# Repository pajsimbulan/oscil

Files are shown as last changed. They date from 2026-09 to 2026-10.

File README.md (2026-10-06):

<p align="center">
  Oscil
</p>

<h3 align="center">A two-channel oscilloscope and function generator, built from three ESP32-S3s</h3>

<p align="center">
  C · ESP-IDF · FreeRTOS · bare-metal drivers · LVGL · KiCad · Supabase
</p>

<p align="center">
  
  
  
  
  
  
</p>

<p align="center">
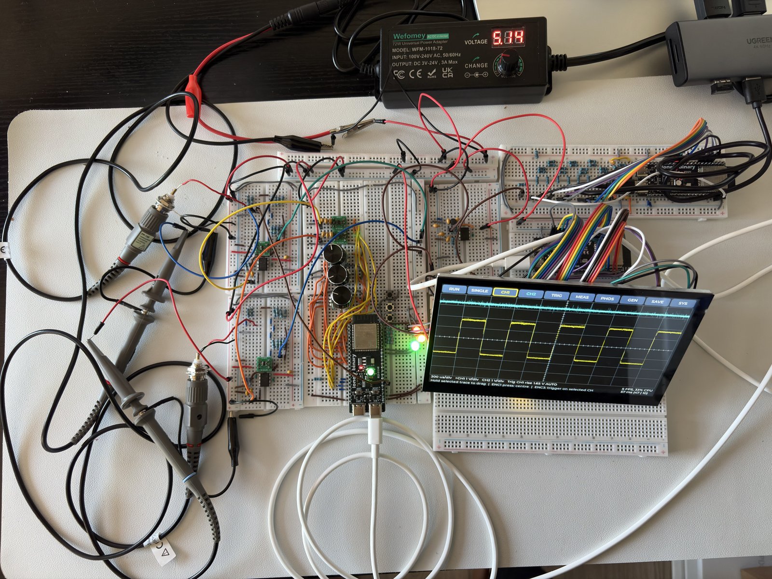
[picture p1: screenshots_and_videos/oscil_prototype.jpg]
The Oscil prototype running on breadboards
  
</p>

Oscil reads two signals and draws them live on a 7 inch touchscreen, and it
can also output sine, square, saw and triangle waves. One board samples,
one runs the screen and one generates. The screen board also joins Wi-Fi,
updates its own firmware and saves screenshots to a cloud account.

I designed and built all of it, the schematic, the breadboard bring-up, the
firmware, the cloud backend and the tests. The build logs below cover every
day of it, bugs included.

**Demos:**
[touch controls](screenshots_and_videos/oscil_touch_controls_demo.mp4) ·
[generator](screenshots_and_videos/oscil_generator_demo.mp4) ·
[firmware update over Wi-Fi](screenshots_and_videos/oscil_ota_update_demo.mp4) ·
[saving to the cloud](screenshots_and_videos/oscil_cloud_save_demo.mp4)

---

## Firmware

| | |
|---|---|
| **Bare-metal drivers** | GPIO, SPI, UART, GDMA and a timer interrupt written from the ESP32-S3 register manual |
| **Sampling** | Two 12-bit ADCs read in one SPI frame at 26.67 MHz, DMA bursts up to about 620 kSa/s, edge trigger, min/max decimation |
| **Board link** | UART at 2 Mbaud with COBS framing and CRC-16, 31.8 frames/s with zero errors |
| **Generator** | DDS in a 100 kHz timer interrupt into an 8-bit R-2R DAC |
| **Display** | LVGL on an 800 x 480 parallel RGB panel, framebuffers in PSRAM, I2C touch |
| **FreeRTOS** | Tasks pinned per core, queues, event groups, notifications, critical sections |
| **Memory** | PSRAM for framebuffers and stacks, code run from PSRAM, ISRs in IRAM, custom partition table, NVS |
| **Connected** | Wi-Fi, HTTPS OTA with self-test and rollback, Supabase sign-in and photo uploads |
| **Tested** | Unity host tests in GitHub Actions, every pin checked on a logic analyzer |

The full list, with the file for each, is in [firmware/README.md](firmware/README.md#firmware-skills).

---

## Repository guide

| Folder | What's inside |
|---|---|
| [`firmware/`](firmware/) | One ESP-IDF project per board, shared C code, host tests, PC tools |
| [`hardware/`](hardware/) | KiCad Rev A schematic, pin map, hardware build log |
| [`software/`](software/) | Supabase schema, account Edge Function, isolation tests |
| [`datasheets/`](datasheets/) | Links to the datasheet revisions the design uses |
| [`screenshots_and_videos/`](screenshots_and_videos/) | Diagrams, photos and demo clips |

---

## Contents

- [Use cases](#use-cases)
- [Architecture](#architecture)
- [Requirements](#requirements)
- [Schematic](#schematic)
- [Build logs](#build-logs)
- [Known limits](#known-limits)
- [What's next](#whats-next)
- [Design documents](#design-documents)
- [Revision history](#revision-history)
- [License](#license)

---

## Use cases

What a user can do with Oscil.

Use cases and functionality

---

## Architecture

Three ESP32-S3 boards linked over UART, with Supabase as the cloud backend.

Architecture

---

## Requirements

### Firmware

How the three ESP32-S3s sample, display, generate and talk to each other.

Firmware requirements

### Hardware

What the hardware has to provide, and why it uses an external ADC and a separate display MCU.

Hardware requirements

### Software

Accounts, screenshot records and file storage on Supabase.

Software requirements

---

## Schematic

Top level of the KiCad Rev A schematic. Each block is its own sheet,
explained in [hardware/](hardware/).

Schematic, top level

**[Full schematic PDF](hardware/docs/Oscil-Schematic-RevA-05-Final.pdf)** ·
[Pin map](hardware/docs/pin-map.md) ·
[Bill of materials](Oscil_bill_of_materials_bom.xlsx)

---

## Build logs

Written as it happened, mistakes included.

<details>
<summary><b>Firmware</b>: from the first blinking LED to cloud saves, with the bugs, the logic analyzer captures and the fixes</summary>

## 2026-09-21

Started firmware. Three ESP-IDF projects, one per board, plus a shared
folder so pin numbers and the link protocol only exist once.

## 2026-09-22

sdkconfig.defaults in each: 16MB flash, octal PSRAM, 1000 Hz tick,
console on USB Serial/JTAG. The 2MB and 100 Hz defaults both bit me
in earlier lab work, so each build gets checked against sdkconfig.

Pin numbers from pin-map.md are in a header per board. Firmware
never uses a raw GPIO number.

AFE scaling in shared. The divider bottom sits on 2.2 V instead of
ground, so 0 V at the BNC reads 1.65 V at the ADC. Vbnc = 4 x (Vadc - 1.65).

First build couldn't find oscil_pins_acq.h. An include path would've
found the header but not compiled the .c, so shared is a real component
now. Also caught display and gen still named project(acq).

Host tests with Unity run the real oscil_afe.c on my PC. 4/4 pass.
They check the math, not the hardware. CI runs them on every push
that touches firmware, and the badge on the README shows the result.

Status LED heartbeat on all three boards. GPIO goes through registers
in oscil_gpio.h, no driver. The WS2812 is bit-banged off the CPU cycle
counter: 24 bits GRB, 0.4 or 0.85 us high in a 1.25 us bit, interrupts
masked for the ~30 us frame. Blink task pinned to core 0.
Acq green, display red, gen blue.

First build died on -Werror=misleading-indentation. A `while (...);`
wait loop with the next line one space off. Empty loops get `{ }` now.
First flash wasn't one either: only the monitor ran, and board 1 was
still booting an old lab.

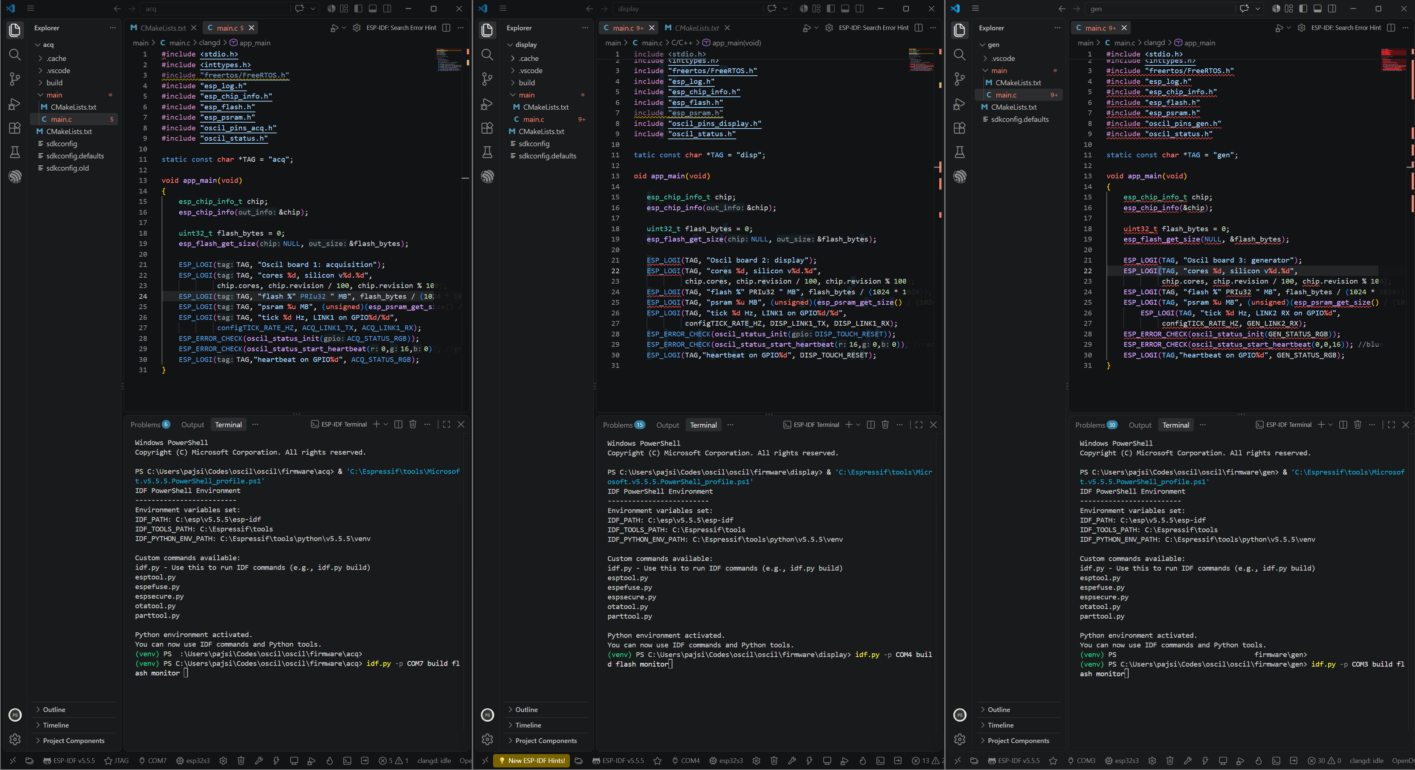
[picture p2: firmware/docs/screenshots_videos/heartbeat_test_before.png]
Before: three projects, one command each


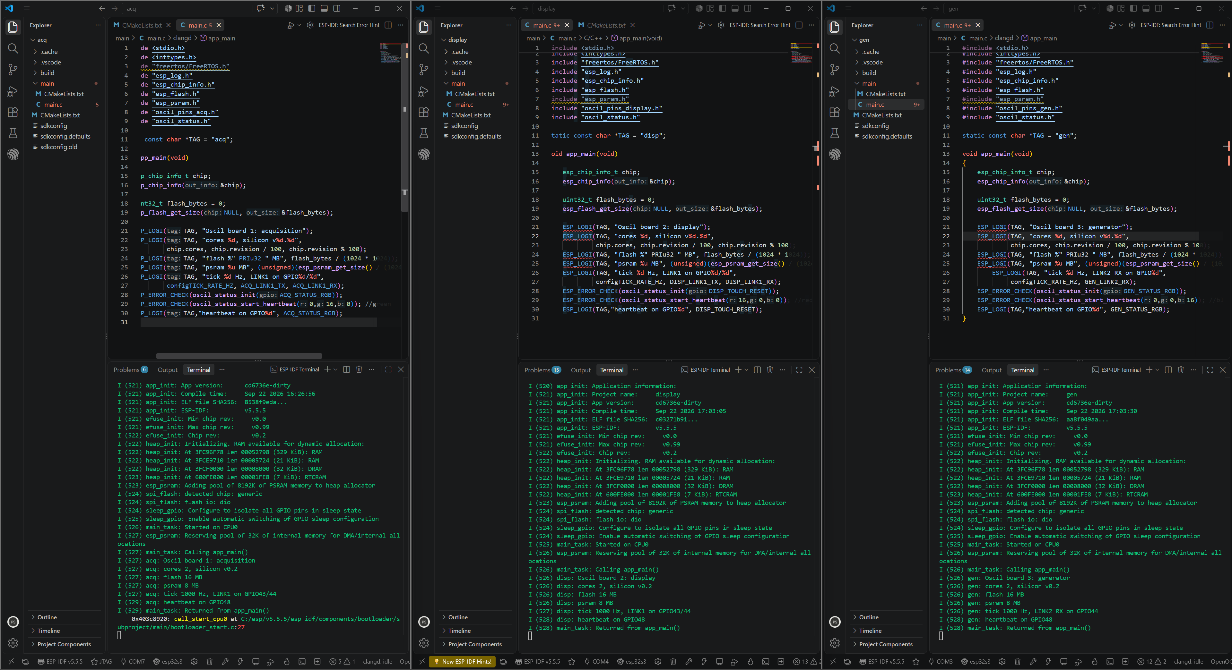
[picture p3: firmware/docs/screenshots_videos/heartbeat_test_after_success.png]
After: all three boot, heartbeat on GPIO48


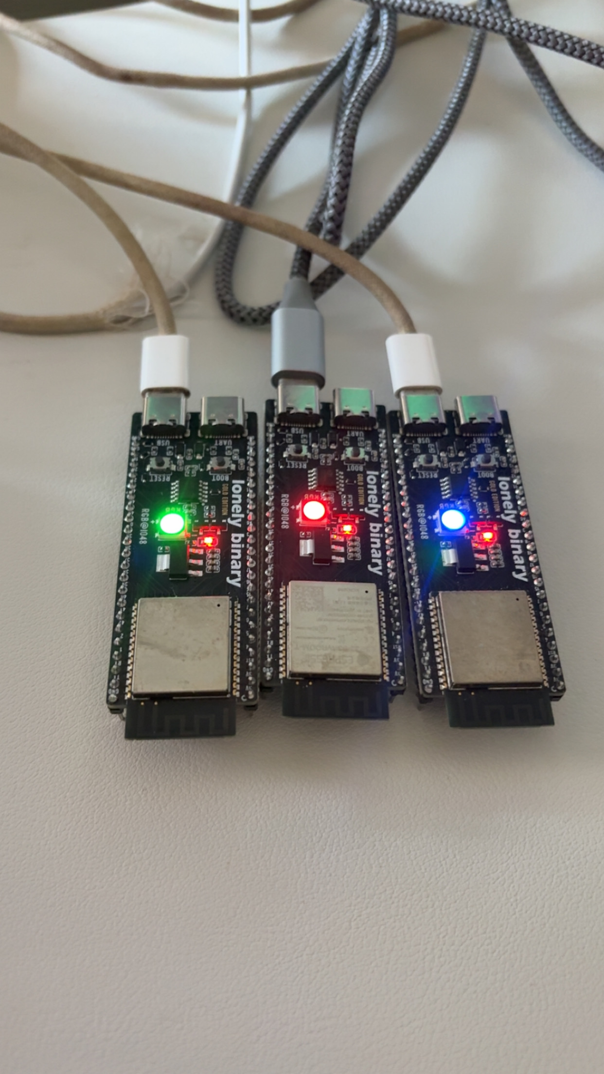
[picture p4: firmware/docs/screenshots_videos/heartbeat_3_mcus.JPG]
Three boards blinking, click for video


Pin walk on board 1. The first pin in the list pulses once, the second
twice, and so on, then every pin is read back with the pull-up on.
26 pins, four batches of eight on the logic analyzer, every count
matched the schematic header. GPIO43 and 44 are the TX and RX pads
on the silkscreen, not numbered.

First read pass came back with random 0s. I was reading right after
turning on the 45k pull-up, and the pin had just been driven low, so it
hadn't charged yet. Pull-ups on for everything, 10 ms settle, then read:
all 1s every pass.

Each batch: analyzer GND to header 22, D0 to D7 on eight header pins,
1 MHz capture. Counting the pulses on a channel tells you which GPIO
is on that pin.

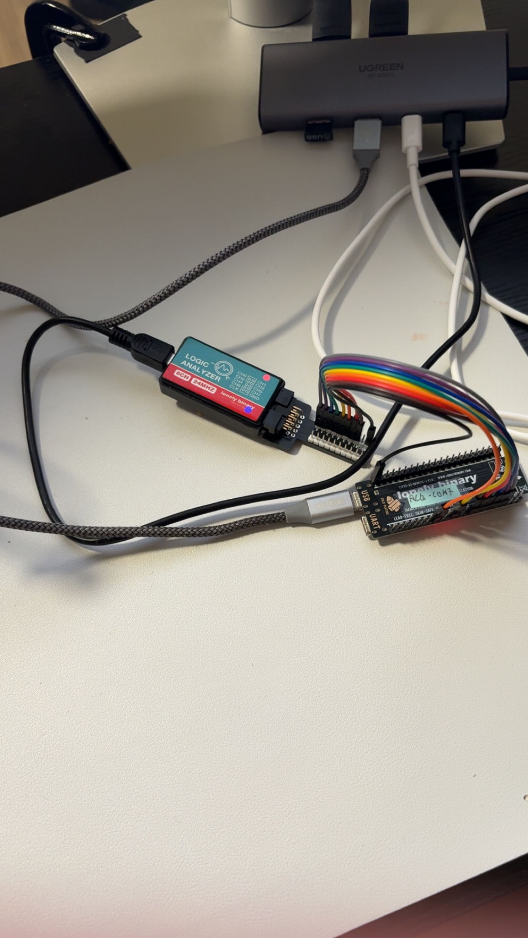
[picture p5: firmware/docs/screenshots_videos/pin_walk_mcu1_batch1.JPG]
Board 1 wired to the analyzer, batch 1


Batch 1:

| Ch | Header | GPIO | Signal | Pulses | Seen |
|---|---|---|---|---|---|
| D0 | 4 | 4 | ENC1_A | 1 | ✓ |
| D1 | 5 | 5 | ENC1_B | 2 | ✓ |
| D2 | 6 | 6 | ENC1_SW | 3 | ✓ |
| D3 | 7 | 7 | ENC2_A | 4 | ✓ |
| D4 | 12 | 8 | ENC2_B | 5 | ✓ |
| D5 | 15 | 9 | ENC2_SW | 6 | ✓ |
| D6 | 8 | 15 | CH2_SCLK | 7 | ✓ |
| D7 | 9 | 16 | CH2_SDO | 8 | ✓ |

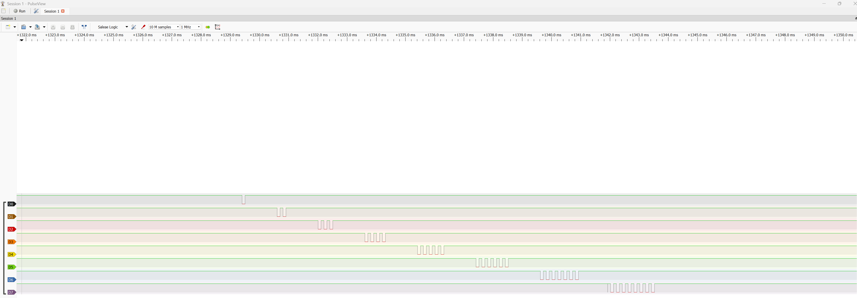
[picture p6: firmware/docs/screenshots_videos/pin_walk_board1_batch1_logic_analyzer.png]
Batch 1: 1 to 8 pulses


Batch 2:

| Ch | Header | GPIO | Signal | Pulses | Seen |
|---|---|---|---|---|---|
| D0 | 10 | 17 | CH2_CS | 9 | ✓ |
| D1 | 16 | 10 | CH1_CS | 10 | ✓ |
| D2 | 11 | 18 | ENC3_A | 11 | ✓ |
| D3 | 18 | 12 | CH1_SCLK | 12 | ✓ |
| D4 | 19 | 13 | CH1_SDO | 13 | ✓ |
| D5 | 27 | 21 | ENC3_B | 14 | ✓ |
| D6 | 35 | 38 | ENC3_SW | 15 | ✓ |
| D7 | 36 | 39 | BTN_RUN | 16 | ✓ |

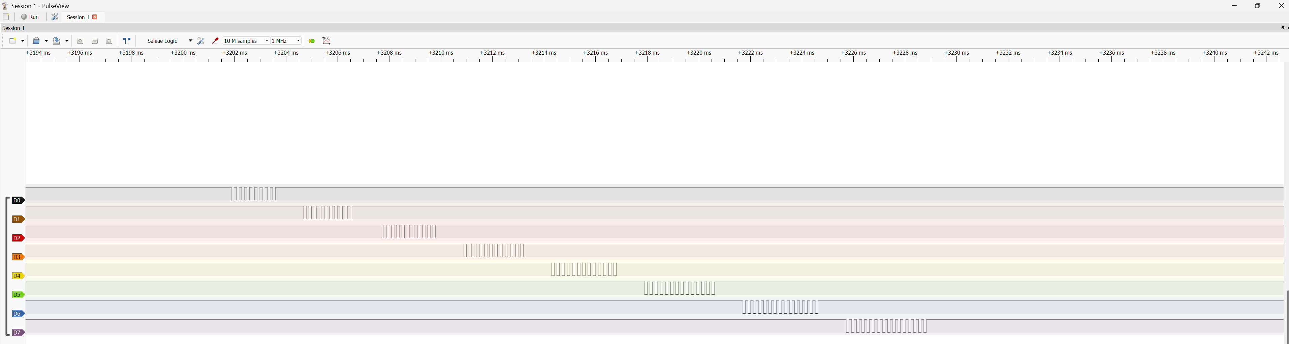
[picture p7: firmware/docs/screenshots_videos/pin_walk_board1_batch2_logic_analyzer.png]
Batch 2: 9 to 16 pulses


Batch 3:

| Ch | Header | GPIO | Signal | Pulses | Seen |
|---|---|---|---|---|---|
| D0 | 37 | 40 | BTN_SINGLE | 17 | ✓ |
| D1 | 38 | 41 | BTN_GEN | 18 | ✓ |
| D2 | 39 | 42 | LED_RUN | 19 | ✓ |
| D3 | 28 | 47 | LED_TRIG | 20 | ✓ |
| D4 | 41 | 1 | LED_ARM | 21 | ✓ |
| D5 | 43 (TX) | 43 | LINK1_TX | 22 | ✓ |
| D6 | 42 (RX) | 44 | LINK1_RX | 23 | ✓ |
| D7 | 40 | 2 | spare | 24 | ✓ |

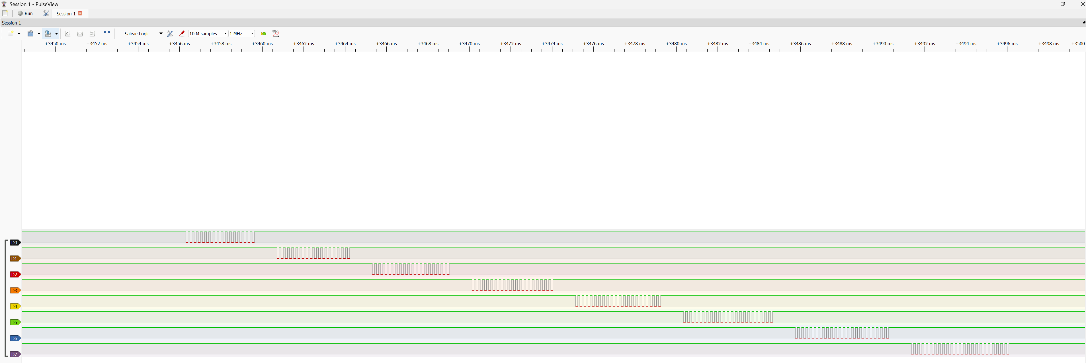
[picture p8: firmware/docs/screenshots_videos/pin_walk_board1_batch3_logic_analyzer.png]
Batch 3: 17 to 24 pulses, TX and RX included


Batch 4:

| Ch | Header | GPIO | Signal | Pulses | Seen |
|---|---|---|---|---|---|
| D0 | 17 | 11 | spare | 25 | ✓ |
| D1 | 20 | 14 | spare | 26 | ✓ |

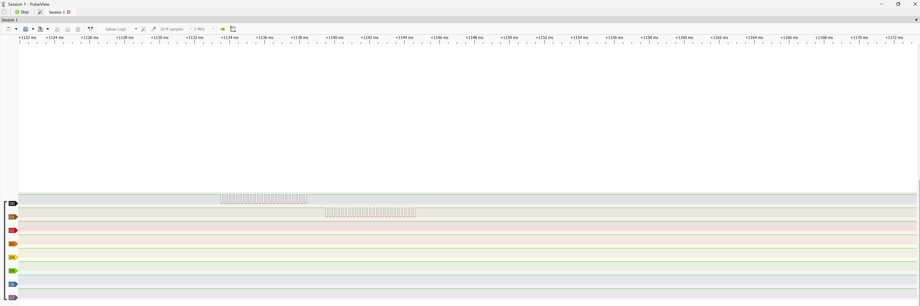
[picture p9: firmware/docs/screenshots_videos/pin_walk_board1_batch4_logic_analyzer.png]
Batch 4: the two spares, 25 and 26


Pin walk on board 2. Same 26-pin idea, same header order as board 1, so
the analyzer wiring for each batch didn't change between boards. Every
count matched. GPIO48 stays off the list: it's the status LED now and
the touch reset later, so it gets checked when the touch panel goes on.

Batch 1:

| Ch | Header | GPIO | Signal | Pulses | Seen |
|---|---|---|---|---|---|
| D0 | 4 | 4 | LCD_R5 | 1 | ✓ |
| D1 | 5 | 5 | LCD_R6 | 2 | ✓ |
| D2 | 6 | 6 | LCD_R7 | 3 | ✓ |
| D3 | 7 | 7 | LCD_G2 | 4 | ✓ |
| D4 | 12 | 8 | LCD_G3 | 5 | ✓ |
| D5 | 15 | 9 | LCD_G4 | 6 | ✓ |
| D6 | 8 | 15 | LCD_B5 | 7 | ✓ |
| D7 | 9 | 16 | LCD_B6 | 8 | ✓ |

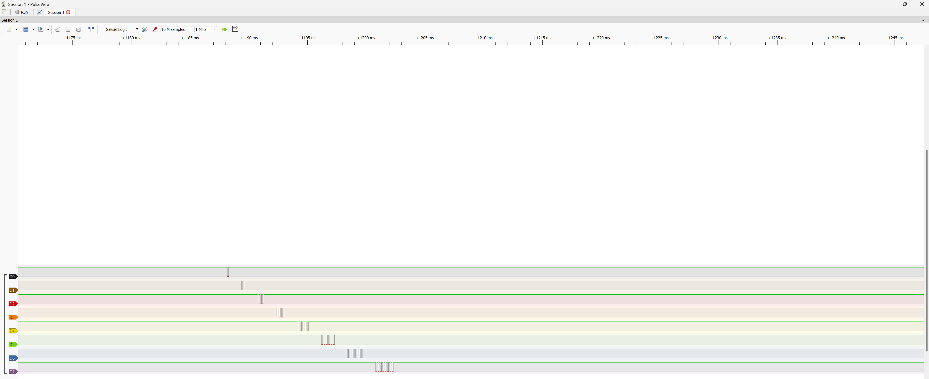
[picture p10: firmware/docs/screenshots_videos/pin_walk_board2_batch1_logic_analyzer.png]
Board 2 batch 1: 1 to 8 pulses, red and green data lines


Batch 2:

| Ch | Header | GPIO | Signal | Pulses | Seen |
|---|---|---|---|---|---|
| D0 | 10 | 17 | LCD_B7 | 9 | ✓ |
| D1 | 16 | 10 | LCD_G5 | 10 | ✓ |
| D2 | 11 | 18 | LCD_DCLK | 11 | ✓ |
| D3 | 18 | 12 | LCD_G7 | 12 | ✓ |
| D4 | 19 | 13 | LCD_B3 | 13 | ✓ |
| D5 | 27 | 21 | LCD_HSYNC | 14 | ✓ |
| D6 | 35 | 38 | LCD_VSYNC | 15 | ✓ |
| D7 | 36 | 39 | LCD_DE | 16 | ✓ |

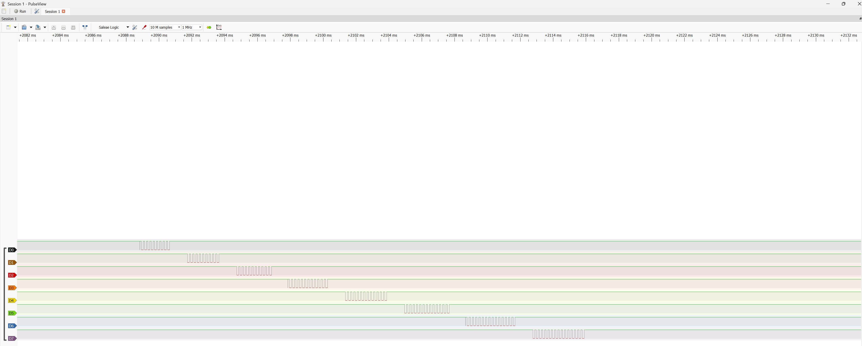
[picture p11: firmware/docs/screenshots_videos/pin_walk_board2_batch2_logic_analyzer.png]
Board 2 batch 2: 9 to 16 pulses, the rest of the RGB bus and its sync lines


Batch 3:

| Ch | Header | GPIO | Signal | Pulses | Seen |
|---|---|---|---|---|---|
| D0 | 37 | 40 | TOUCH_SDA | 17 | ✓ |
| D1 | 38 | 41 | TOUCH_SCL | 18 | ✓ |
| D2 | 39 | 42 | TOUCH_INT | 19 | ✓ |
| D3 | 28 | 47 | LINK2_TX | 20 | ✓ |
| D4 | 41 | 1 | LCD_R3 | 21 | ✓ |
| D5 | 43 (TX) | 43 | LINK1_TX | 22 | ✓ |
| D6 | 42 (RX) | 44 | LINK1_RX | 23 | ✓ |
| D7 | 40 | 2 | LCD_R4 | 24 | ✓ |

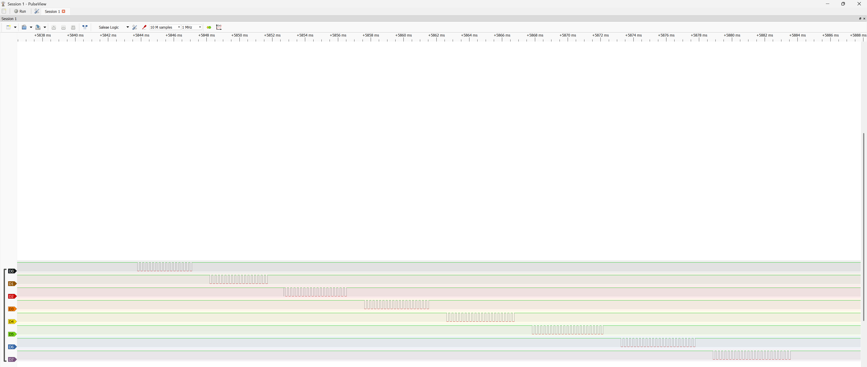
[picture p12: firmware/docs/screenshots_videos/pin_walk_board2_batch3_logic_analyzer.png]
Board 2 batch 3: 17 to 24 pulses, touch, both links, two red lines


Batch 4:

| Ch | Header | GPIO | Signal | Pulses | Seen |
|---|---|---|---|---|---|
| D0 | 17 | 11 | LCD_G6 | 25 | ✓ |
| D1 | 20 | 14 | LCD_B4 | 26 | ✓ |

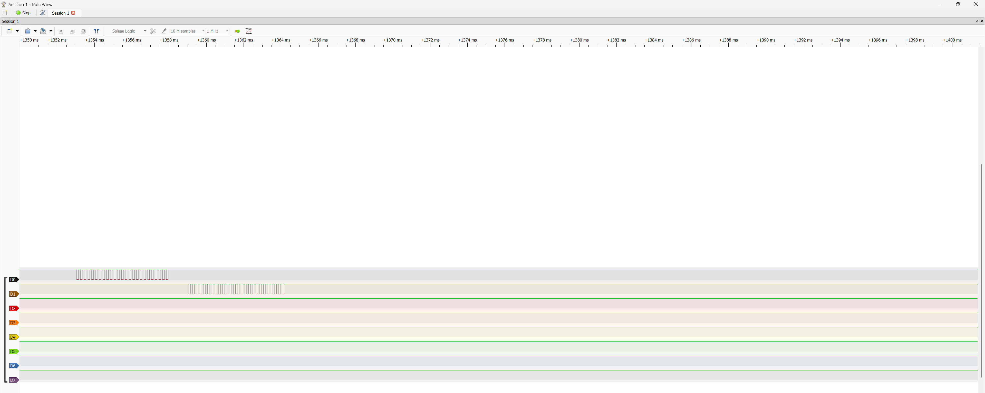
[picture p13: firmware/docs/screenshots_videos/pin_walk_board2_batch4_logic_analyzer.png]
Board 2 batch 4: 25 and 26


Pin walk on board 3. Only nine pins: the eight R-2R bits and LINK2's
receive line. The DAC bits are the ones that have to be exact, since
all eight get written in one store to GPIO_OUT later. All eight matched,
and LINK2_RX on the RX pad showed its 9 pulses. Pin walk done on all
three boards, 61 pins, no mismatches.

| Ch | Header | GPIO | Signal | Pulses | Seen |
|---|---|---|---|---|---|
| D0 | 4 | 4 | DAC_D0 | 1 | ✓ |
| D1 | 5 | 5 | DAC_D1 | 2 | ✓ |
| D2 | 6 | 6 | DAC_D2 | 3 | ✓ |
| D3 | 7 | 7 | DAC_D3 | 4 | ✓ |
| D4 | 12 | 8 | DAC_D4 | 5 | ✓ |
| D5 | 15 | 9 | DAC_D5 | 6 | ✓ |
| D6 | 16 | 10 | DAC_D6 | 7 | ✓ |
| D7 | 17 | 11 | DAC_D7 | 8 | ✓ |
| D0 (batch 2) | 42 (RX) | 44 | LINK2_RX | 9 | ✓ |

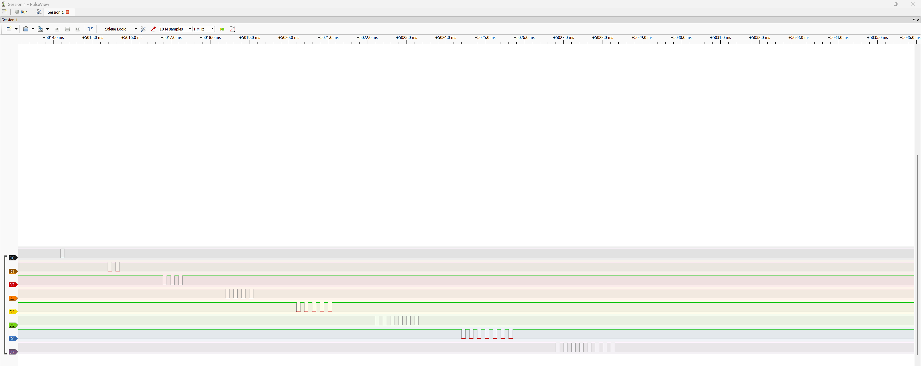
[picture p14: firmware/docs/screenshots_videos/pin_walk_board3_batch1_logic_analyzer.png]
Board 3 batch 1: the eight DAC bits, 1 to 8 pulses


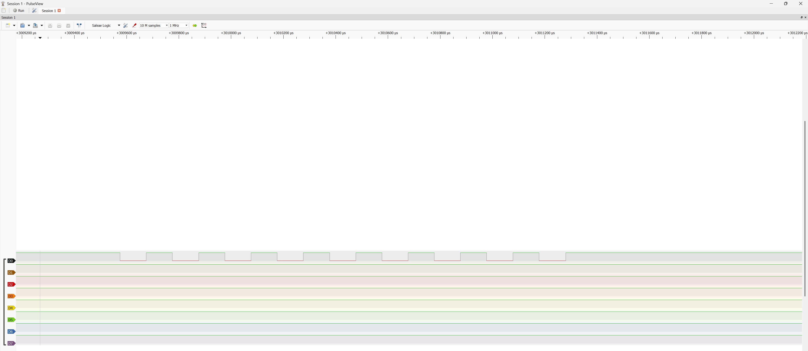
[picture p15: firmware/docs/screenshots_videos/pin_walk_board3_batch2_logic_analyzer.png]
Board 3 batch 2: LINK2_RX, 9 pulses


## 2026-09-23

Wrote the SPI side for the ADCs: GP-SPI2 set up straight from its
registers, no driver. Clock on, pins on the IO MUX, 80 MHz module clock
divided down, mode 1, 16 clocks per frame, single or dual line. The
fastest legal clock is 26.67 MHz (80 MHz / 3), since /2 would be 40 and
the ADS7883 tops out at 32 at 3.3 V.

Speed test is written too: times 10,000 frames on the cycle counter for
five settings and holds each for 2 s so the analyzer can catch it.
Nothing plugged in yet, the analyzer run is next.

## 2026-09-24

Ran the speed test on board 1. JTAG flashing kept failing in OpenOCD,
so flashed over UART on COM7 instead.

First run tripped the task watchdog: the 2 s hold loop spun and IDLE0
never ran. It yields every 500 frames now. The result lines also went
missing until I added a 10 ms delay after unmasking interrupts, plus
fflush.

| SCLK | Mode | Lines | Cycles/frame | ns/frame | kSa/s |
|---|---|---|---|---|---|
| 10 MHz | 1 | single | 525 | 2188 | 457 |
| 10 MHz | 1 | dual | 525 | 2188 | 457 |
| 26.67 MHz | 0 | single | 261 | 1088 | 919 |
| 26.67 MHz | 1 | single | 261 | 1088 | 919 |
| 26.67 MHz | 1 | dual | 261 | 1088 | 919 |

At 26.67 MHz the 16 clocks take 600 ns, so about 490 ns of each frame
is overhead from the CPU starting each frame. DMA fixes that later.
Dual line costs nothing, so it's Plan B: one SCLK and CS for both ADCs,
CH1 on GPIO13, CH2 on GPIO11.

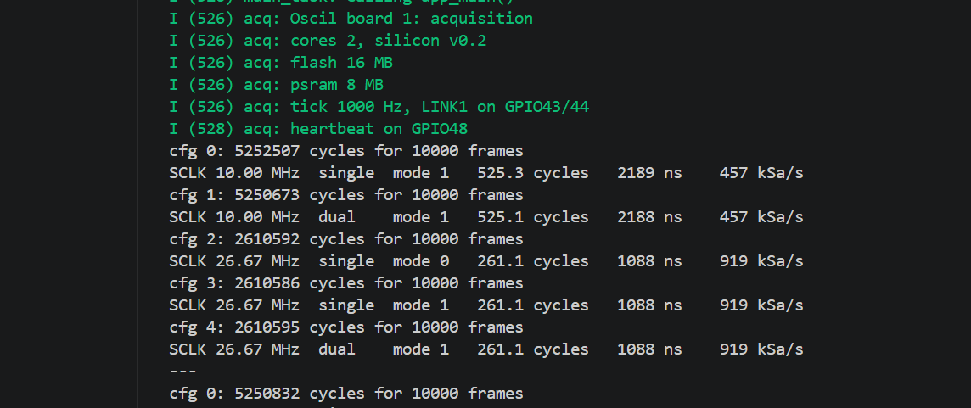
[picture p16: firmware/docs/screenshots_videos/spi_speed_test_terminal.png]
Speed test output on the monitor


Analyzer on board 1, 24 MHz sample rate:

| Analyzer | GPIO | Signal |
|---|---|---|
| D0 | 12 | SCLK |
| D1 | 10 | CS |

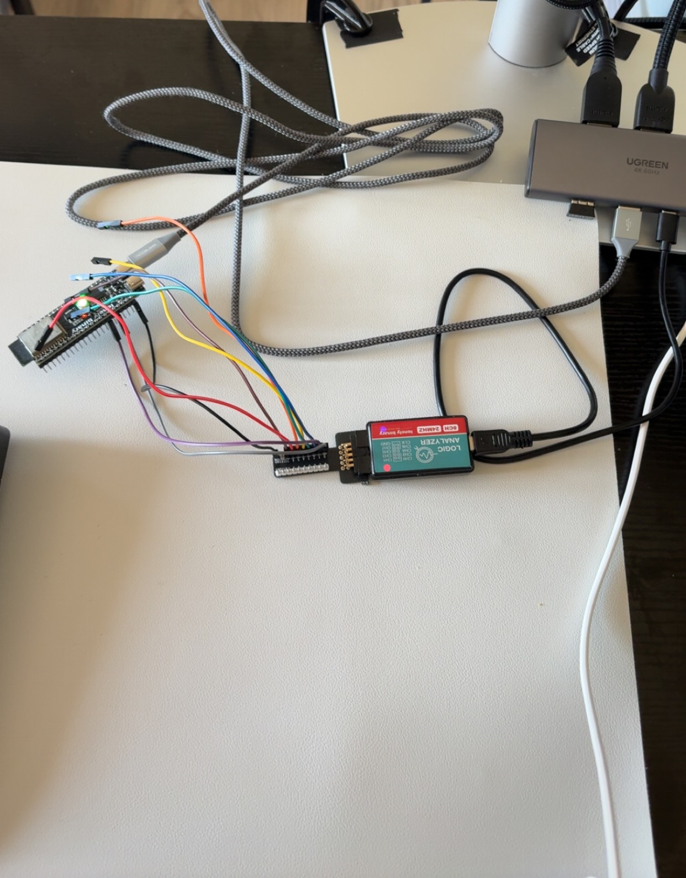
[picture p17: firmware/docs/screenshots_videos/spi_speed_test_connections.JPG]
Analyzer wired to board 1


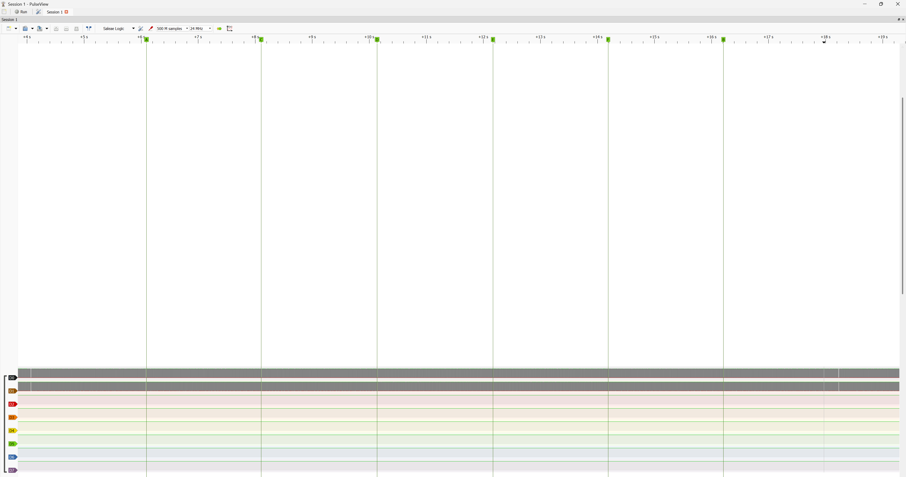
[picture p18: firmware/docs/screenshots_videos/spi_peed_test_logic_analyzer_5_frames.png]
Five frames back to back


10 MHz: CS period 2208 ns, matches the 2188 from the cycle counter.
16 clocks per frame.

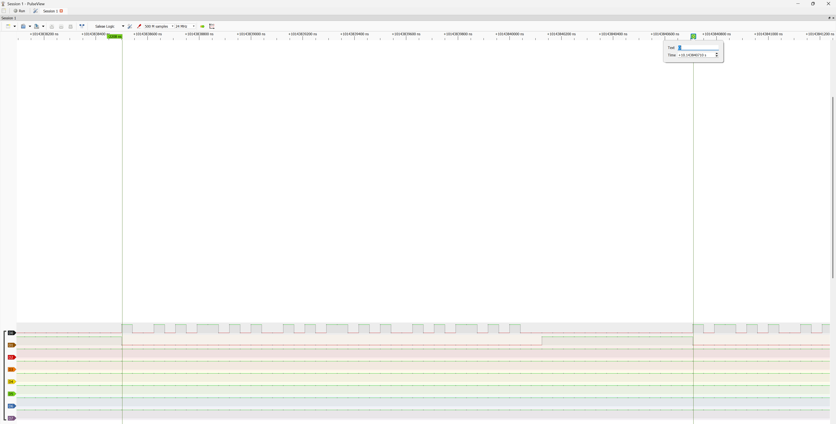
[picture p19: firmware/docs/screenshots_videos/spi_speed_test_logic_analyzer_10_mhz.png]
10 MHz block, 16 clocks inside one CS low


26.67 MHz: CS period 1084 ns, matches 1088. The clock itself aliases at
24 MHz sampling, so the CS period is the proof here, not the edges.

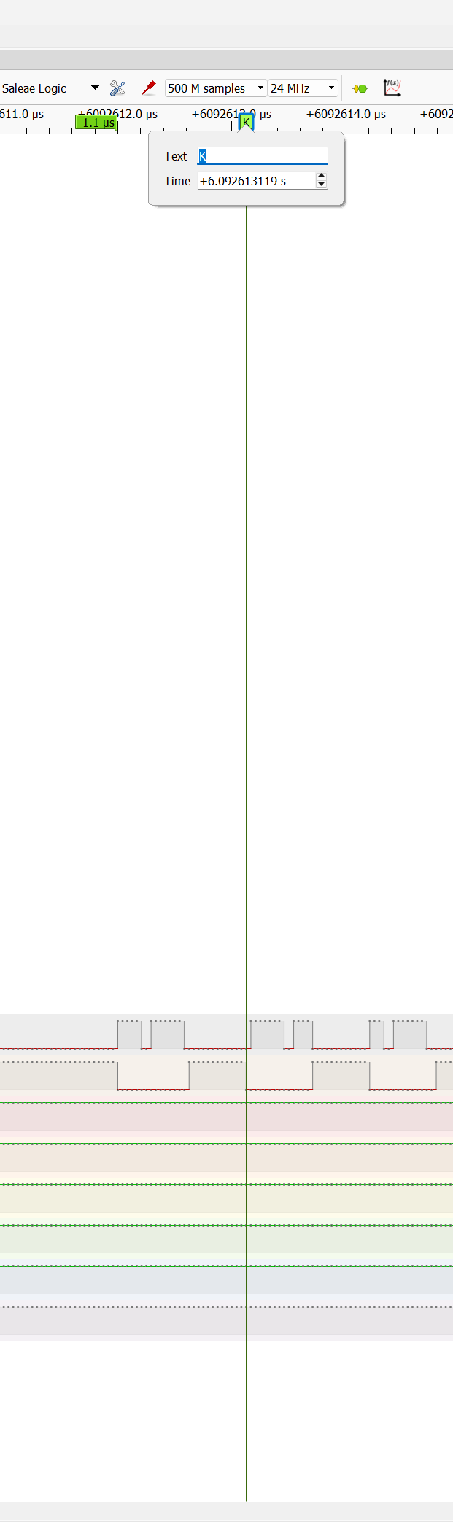
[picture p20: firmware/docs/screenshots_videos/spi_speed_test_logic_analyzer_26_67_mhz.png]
26.67 MHz block, CS period


The analog rail. MCP1700 on the breadboard, 1 uF ceramics for
C1 and C2 from the MLCC kit, jumper wire for R1. Nothing else on
+3V3_A yet.

+5V comes from the ELEGOO breadboard power module for now instead of
board 1's 5V pin, so the USB backfeed check is skipped. Its USB-C input
only gave 4.648 V (passthrough plus the drops along the way). The
barrel jack goes through the module's own regulator and gives 4.987 V,
so that's what I'm using.

| Node | Reading |
|---|---|
| +5V_A (VIN) | 4.987 V |
| +3V3_A (VOUT) | 3.314 V |

3.314 V is 0.4% high, well inside the MCP1700's +/-3% spec.

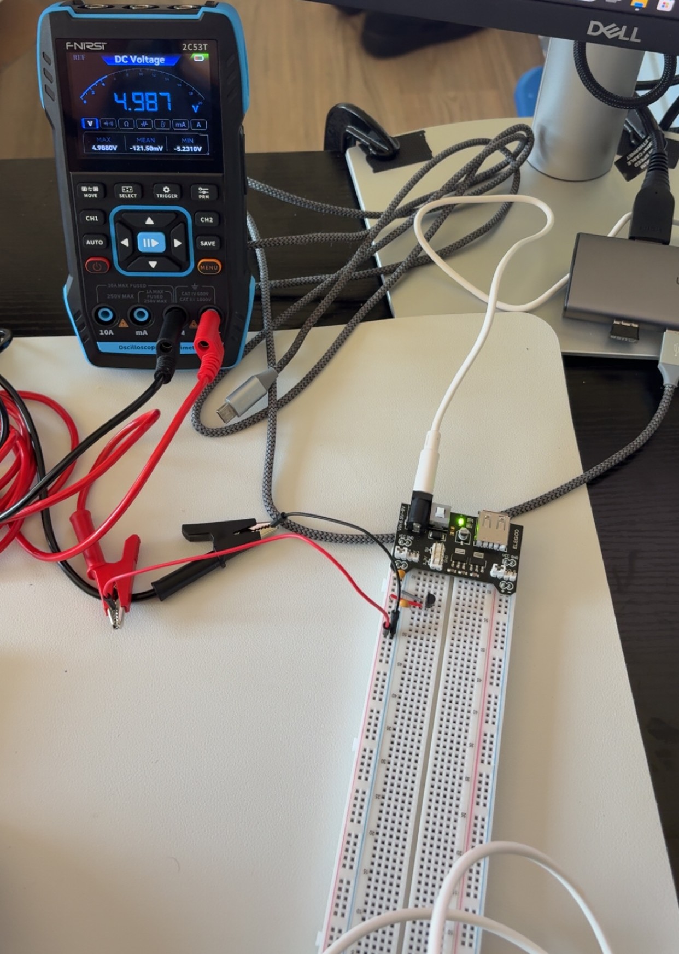
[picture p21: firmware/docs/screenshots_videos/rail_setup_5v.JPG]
+5V_A from the barrel jack


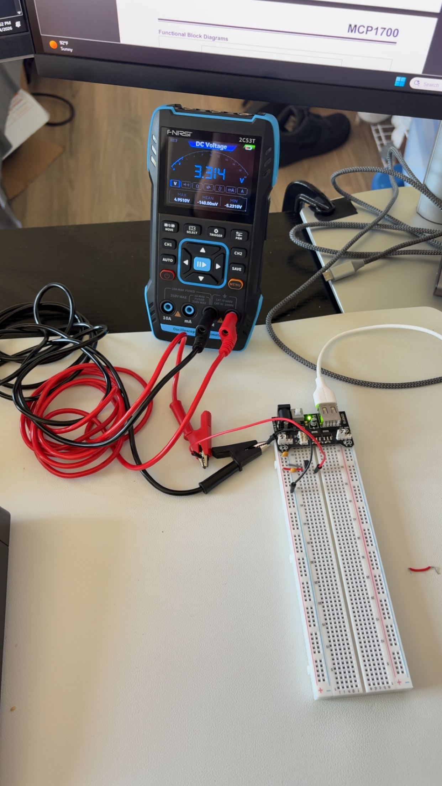
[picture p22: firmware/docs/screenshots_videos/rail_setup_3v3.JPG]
+3V3_A at the MCP1700 output


The 2.2 V reference. R2/R3 (10k/20k) off +3V3_A with C3 on
the midpoint, U2A as a unity-gain buffer, C4 right on pin 8. U2B is
parked as a follower with its input on GND, same as the schematic.

| Node | Reading |
|---|---|
| Divider (pin 3) | 2.214 V |
| VREF_2V2 (pin 1) | 2.214 V |

Expected 3.314 x 20k/30k = 2.209 V, so 5 mV off, inside 1% resistor
tolerance. Pin 1 matches pin 3, so the buffer adds nothing.

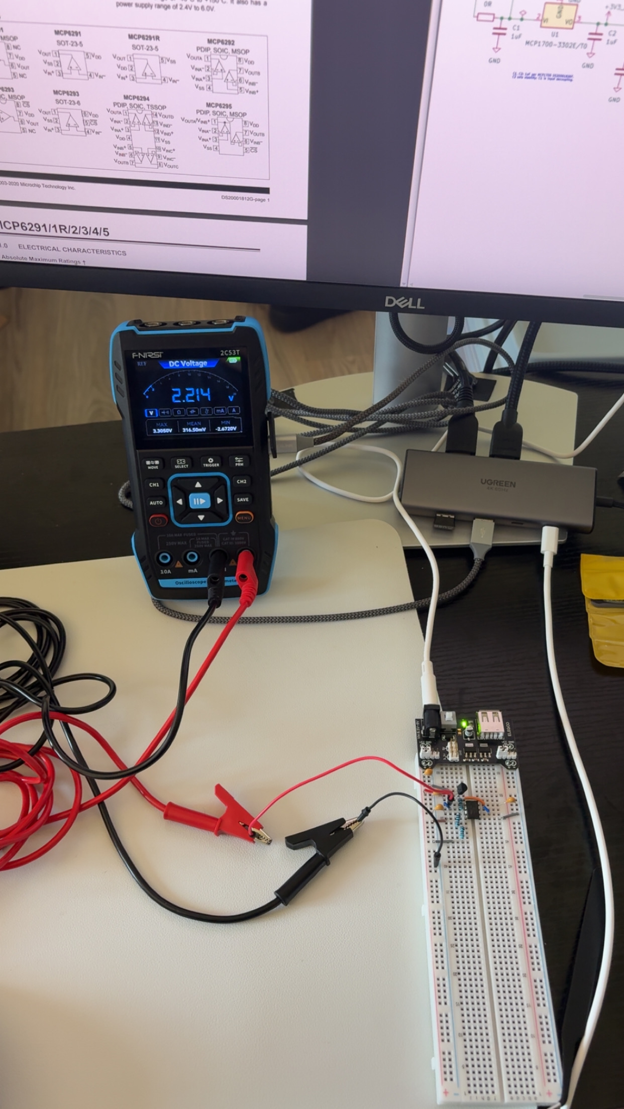
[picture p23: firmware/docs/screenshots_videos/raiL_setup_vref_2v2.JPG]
VREF_2V2 at the buffer output


Prep for the front end: the parts that don't fit a breadboard.

BNCs (Superbat panel mount) got jumper wires soldered on: centre pin for
signal, solder lug for ground. Continuity centre to jack pin and lug to
barrel beep, centre to shell reads OL.

BAV99s are SOT-23-3, so they went on the adapter boards. Tiny and
sloppy without proper tools, but continuity passes. The adapter
silkscreen doesn't match the part:

| BAV99 pin | Job | Adapter pad |
|---|---|---|
| 1 | lower anode, to GND | 6 |
| 2 | upper cathode, to +3V3_A | 2 |
| 3 | common, to JCT | 4 |

One of the two has pins 2 and 3 bridged. That shorts the upper diode
and ties JCT straight to +3V3_A, so it's not going in until the bridge
is cleaned up.

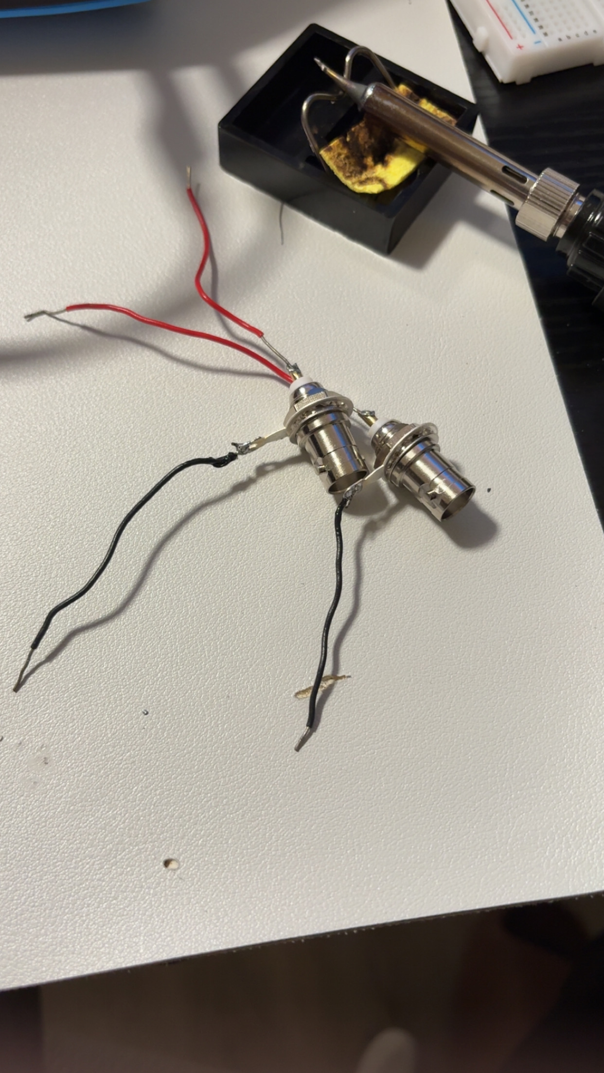
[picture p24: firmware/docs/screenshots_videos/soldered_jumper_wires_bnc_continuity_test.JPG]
BNC with soldered leads, continuity


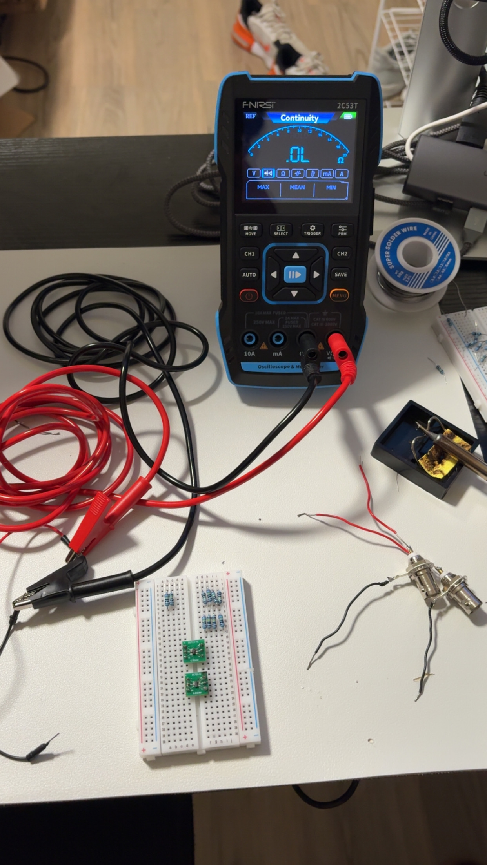
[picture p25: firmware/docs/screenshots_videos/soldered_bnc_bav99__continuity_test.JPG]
BNCs and BAV99 adapters, continuity


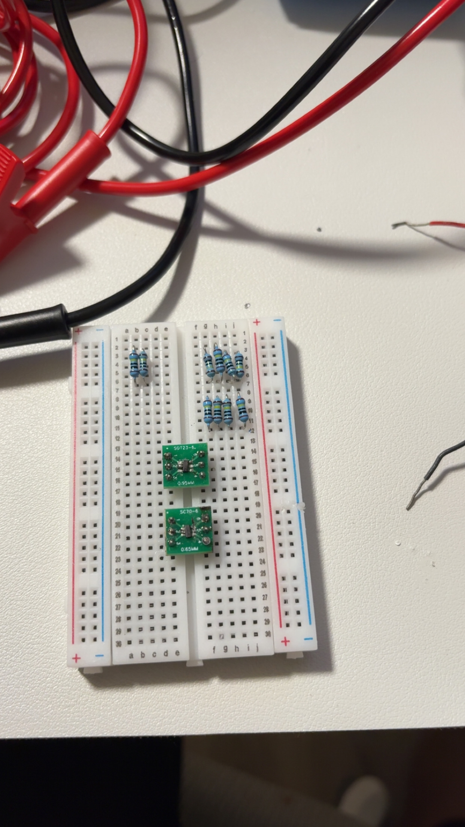
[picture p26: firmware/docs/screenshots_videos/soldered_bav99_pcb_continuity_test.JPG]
BAV99s on their adapters


CH1 front end on the breadboard: R4 750k, R5 250k to VREF_2V2, BAV99
clamp, U3A buffer. Trimmers and the ADC filter stay off for now. Output
measured at U3 pin 1.

| Input | Expected | Measured |
|---|---|---|
| Nothing connected | 2.21 V (no current, so it sits at VREF) | 2.2 V |
| IN to GND | 1.66 V (0.75 x VREF) | 1.66 V |

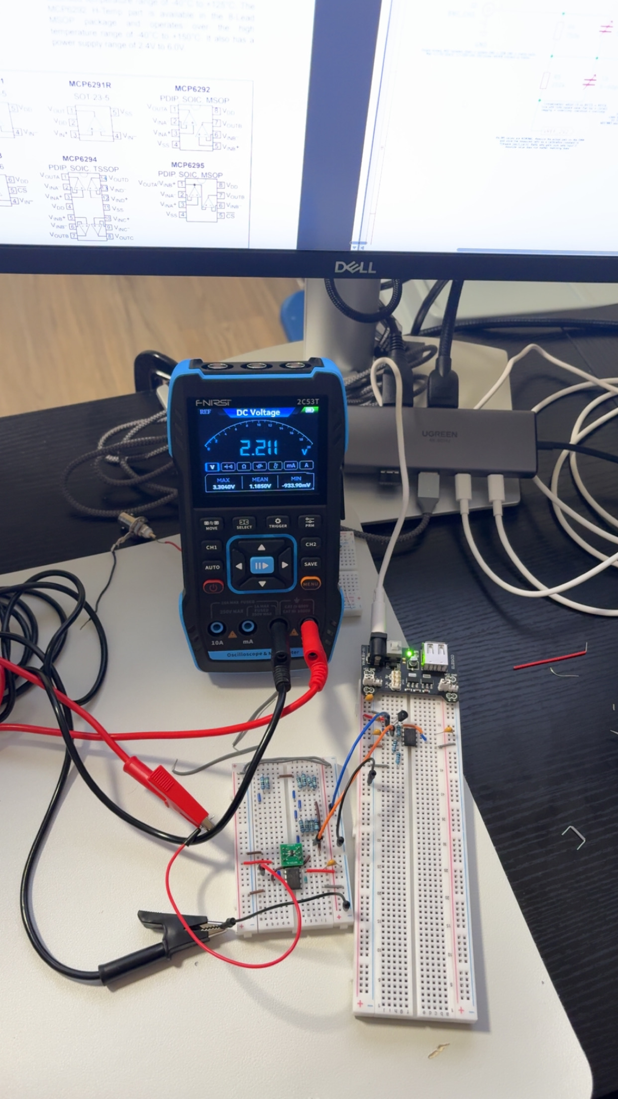
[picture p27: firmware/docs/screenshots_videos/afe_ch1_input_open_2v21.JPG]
Input open, output at VREF


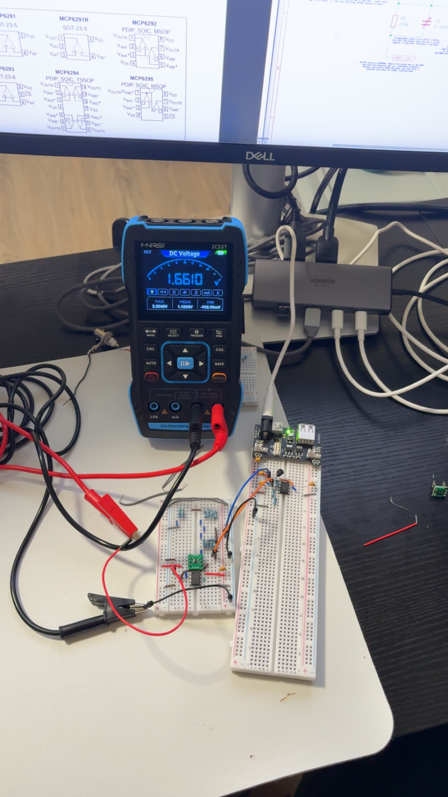
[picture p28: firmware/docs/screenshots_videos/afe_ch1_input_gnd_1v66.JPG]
Input grounded, output at the 1.66 V offset


CH2 front end, same circuit: R7 750k, R8 250k to VREF_2V2, the second
BAV99, U4A buffer. Output measured at U4 pin 1.

| Input | Expected | Measured |
|---|---|---|
| Nothing connected | 2.21 V | 2.21 V |
| IN to GND | 1.66 V | 1.66 V |

Both channels match each other and the math.

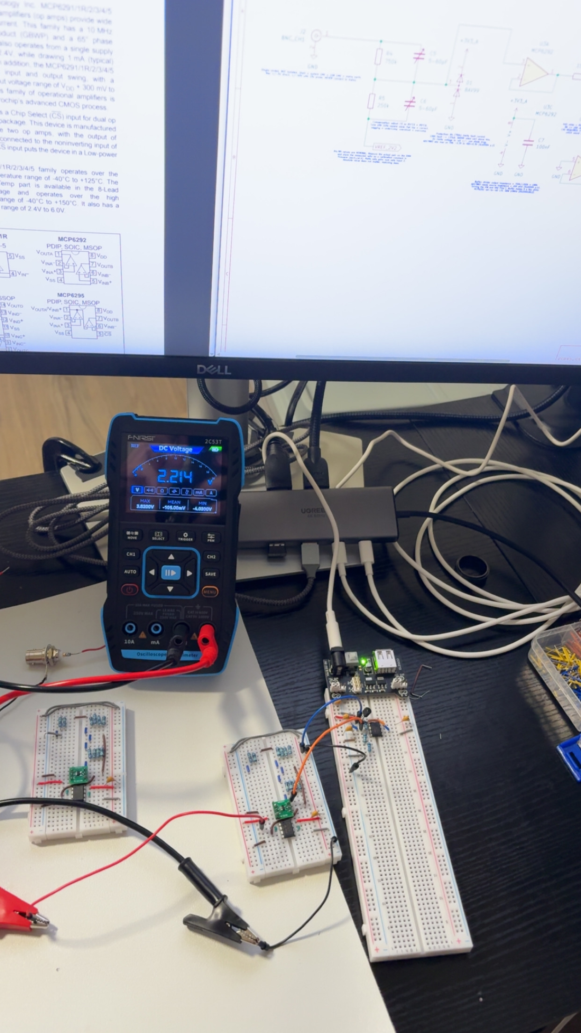
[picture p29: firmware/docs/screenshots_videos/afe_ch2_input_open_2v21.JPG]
CH2 input open, output at VREF


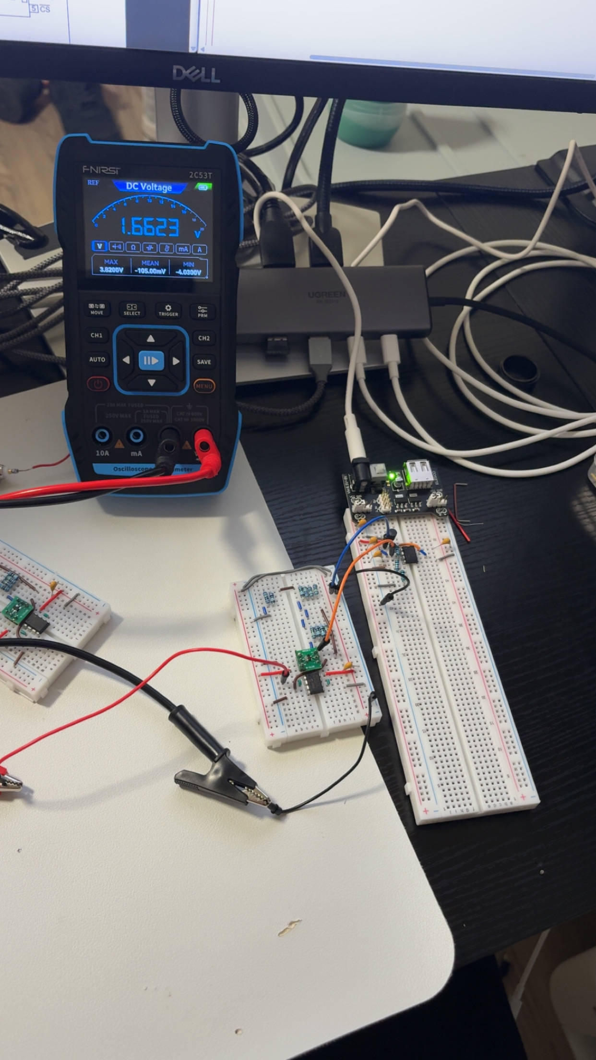
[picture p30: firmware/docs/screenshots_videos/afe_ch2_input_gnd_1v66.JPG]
CH2 input grounded, output at the 1.66 V offset


## 2026-09-25

Front panel on board 1: three LEDs and three buttons on their own
breadboard, wired to the board's headers.

Moved LED_TRIG from GPIO47 to GPIO2 first. There was no reason for it
to sit apart from the other two, and now the LEDs are on headers 39-41
right above the buttons on 36-38. Schematic, pin map and pin header
updated together.

| Part | GPIO | Header | Notes |
|---|---|---|---|
| LED_RUN (green) | 42 | 39 | 330R, active high |
| LED_TRIG (yellow) | 2 | 40 | 330R, active high |
| LED_ARM (red) | 1 | 41 | 330R, active high |
| BTN_RUN | 39 | 36 | to GND, internal 45k pull-up |
| BTN_SINGLE | 40 | 37 | to GND, internal 45k pull-up |
| BTN_GEN | 41 | 38 | to GND, internal 45k pull-up |

panel.c polls all six inputs (the three buttons plus the encoder
switches) every 1 ms and only takes a change after 20 scans in a row
agree, so bounce never gets through. Each clean press or release goes
on a FreeRTOS queue as an event. Polling instead of edge interrupts:
the 20 ms debounce sets the response time either way, and a bouncing
contact would fire dozens of interrupts per press.

The test prints every event and toggles an LED per button. One press
and one release per push, no doubles.

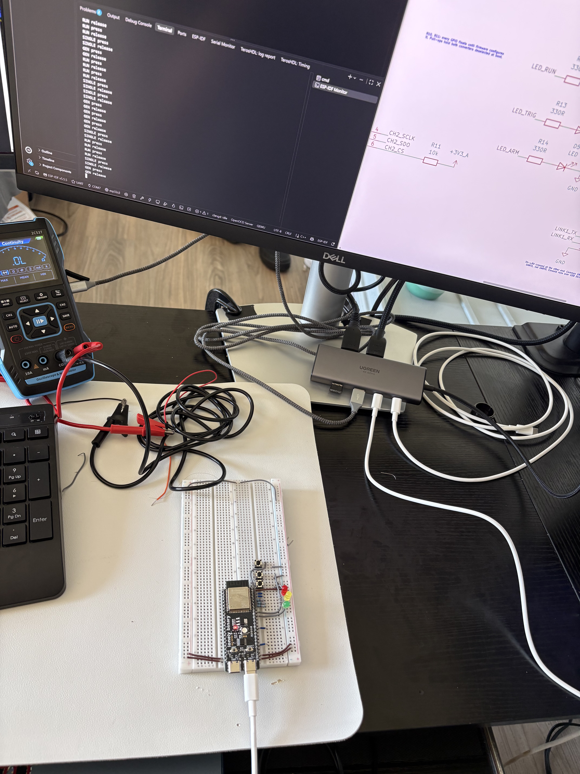
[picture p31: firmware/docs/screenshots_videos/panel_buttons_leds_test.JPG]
Panel test running, events on the monitor


[Video: buttons toggling the LEDs](firmware/docs/screenshots_videos/panel_buttons_leds_test.MP4)

Put the dual-line SPI decision into the schematic and pin map. Both
ADCs now share one clock and one chip select on SPI2's IO MUX pins, and
CH2's data comes in on GPIO11 (FSPID) next to CH1's on GPIO13 (FSPIQ).
The old second bus on GPIO15-17 is gone, and so is R11: one 10k pull-up
on the shared CS covers both converters.

That freed three pins right where the encoders were scattered, so the
encoders moved too. All nine encoder lines now sit on headers 4-12, one
knob after another.

| Signal | Was | Now | Header |
|---|---|---|---|
| ADC_SCLK | 12 (CH1) + 15 (CH2) | 12 | 18 |
| ADC_CS | 10 (CH1) + 17 (CH2) | 10 | 16 |
| CH1_SDO | 13 | 13 | 19 |
| CH2_SDO | 16 | 11 | 17 |
| ENC2_B | 8 | 15 | 8 |
| ENC2_SW | 9 | 16 | 9 |
| ENC3_A | 18 | 17 | 10 |
| ENC3_B | 21 | 18 | 11 |
| ENC3_SW | 38 | 8 | 12 |

Spares now 9, 14, 21, 38, 47. Nothing was wired to the old pins yet, so
this is paper only, the encoders get checked on the new pins when they
count.

Three EC11 encoders on the panel breadboard, on the new pins (headers
4-12). Each one: A and B to their GPIOs, the middle pin C to GND, push
switch between its SW GPIO and GND. Internal pull-ups, no extra parts.

The decoder is a 16-entry table indexed by the last and current A/B
state, run in the same 1 ms scan as the buttons. A legal step gives +1
or -1, no change or an illegal jump gives 0. Contact bounce toggles one
line back and forth, which reads as +1, -1, +1, -1 and cancels, so
there's no separate debounce. Four steps make one detent on these
(one full A/B cycle per click), and only whole detents become events.

One click prints enc1 +1, back prints enc1 -1, on all three knobs.
The knob presses come through the button code as ENC1-3 press/release.

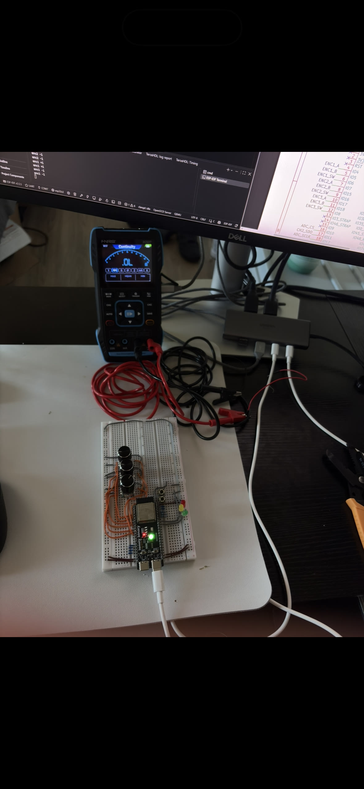
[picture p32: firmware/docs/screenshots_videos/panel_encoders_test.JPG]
Encoders, buttons and LEDs on the panel breadboard


[Video: turning and pressing the knobs](firmware/docs/screenshots_videos/panel_encoders_test.MP4)

## 2026-09-26

Soldered both ADS7883s onto SOT23-6 adapters. Took about four hours,
with no magnifier, no clamps or helping hands, and 0.8 mm solder, which
is too thick for 0.95 mm pitch. Lost two chips along the way, two made
it, which is what the design needs.

What finally worked: tin one corner pad only, hold the chip with
tweezers, reflow that blob to tack one leg, then do the opposite
corner, then the rest. Once one leg is down the chip stops moving.
Headers went on first with the breadboard as a jig, chip after.

Checks on both boards, nothing powered yet:

- Continuity from every chip leg to its header pin: all six pass.
- Adjacent pins shorted: none.
- Orientation from the diode test on the first chip: pin 2 conducts to
  every other pin with the red probe on it, so it's GND and the chip
  is the right way round.

Next time: 0.5 mm solder, tacky flux paste and fine tweezers.

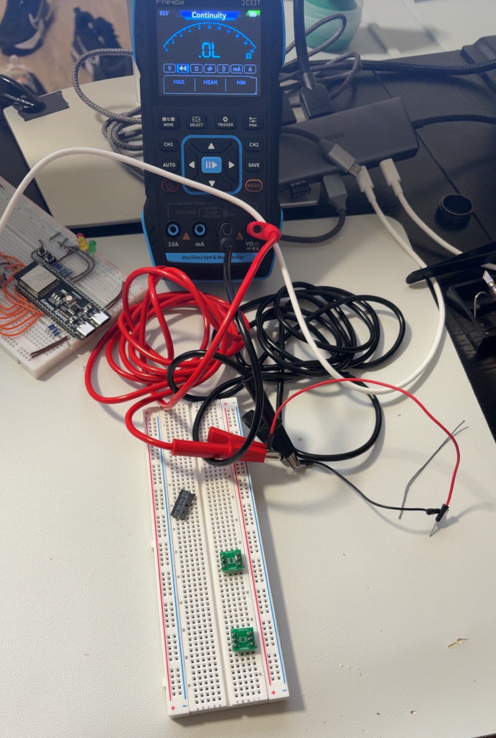
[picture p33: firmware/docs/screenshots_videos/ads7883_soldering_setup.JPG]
Soldering setup


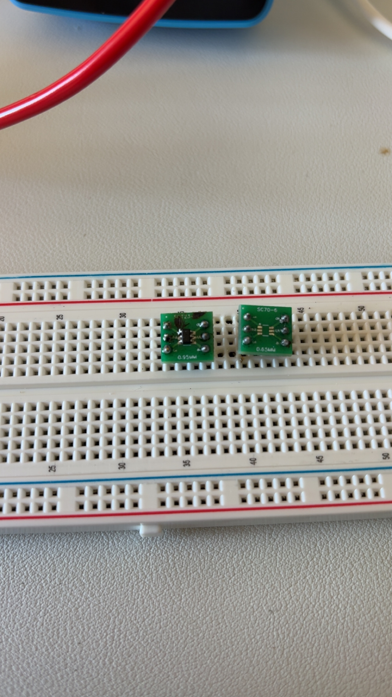
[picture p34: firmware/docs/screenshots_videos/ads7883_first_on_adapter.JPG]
First ADS7883 on its adapter, next to a bare SC70 one


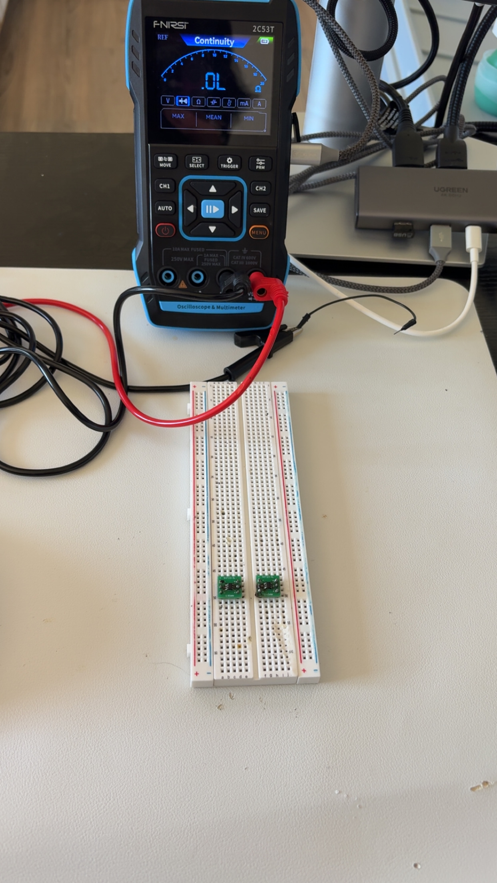
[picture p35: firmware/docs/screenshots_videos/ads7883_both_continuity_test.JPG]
Both ADS7883 adapters, continuity checks


Wired both ADCs into the front ends. U6 on CH1, U7 on CH2, sharing
SCLK (IO12) and CS (IO10), data on IO13 and IO11. R6/R9 are two 330R in
parallel (165R) instead of 150R, still under the ADS7883's 200R source
limit. C8/C9 and C13/C14 (2.2 nF) are on each ADC input. Trimmers and
BNCs still off, IN is a jumper for now.

Both chips are soldered 180 degrees round on their adapters, so the
silkscreen is off by three: chip pins 1-6 are silk 4, 5, 6, 1, 2, 3.
Wired by chip pin, not silkscreen.

First read with the single-line test: code 0.0 on every frame, which
prints as -6.644 V at the BNC. The firmware checks out, and 0 is what
the ADC should report for 0 V in, so the problem is upstream. VREF
wasn't connected to the dividers at first, with that fixed, the R4/R5
junction reads 1.63 V as expected, but VIN at the ADC was still near
0 V. Swapping the two ADCs gave the same result. Still tracing.

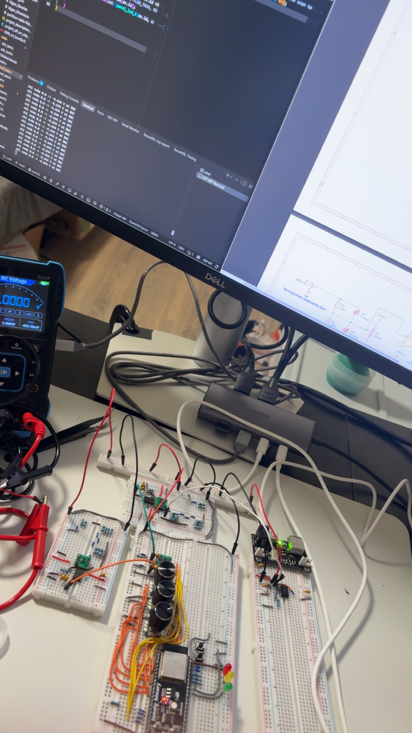
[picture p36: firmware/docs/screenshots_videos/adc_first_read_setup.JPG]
Setup for the first ADC read


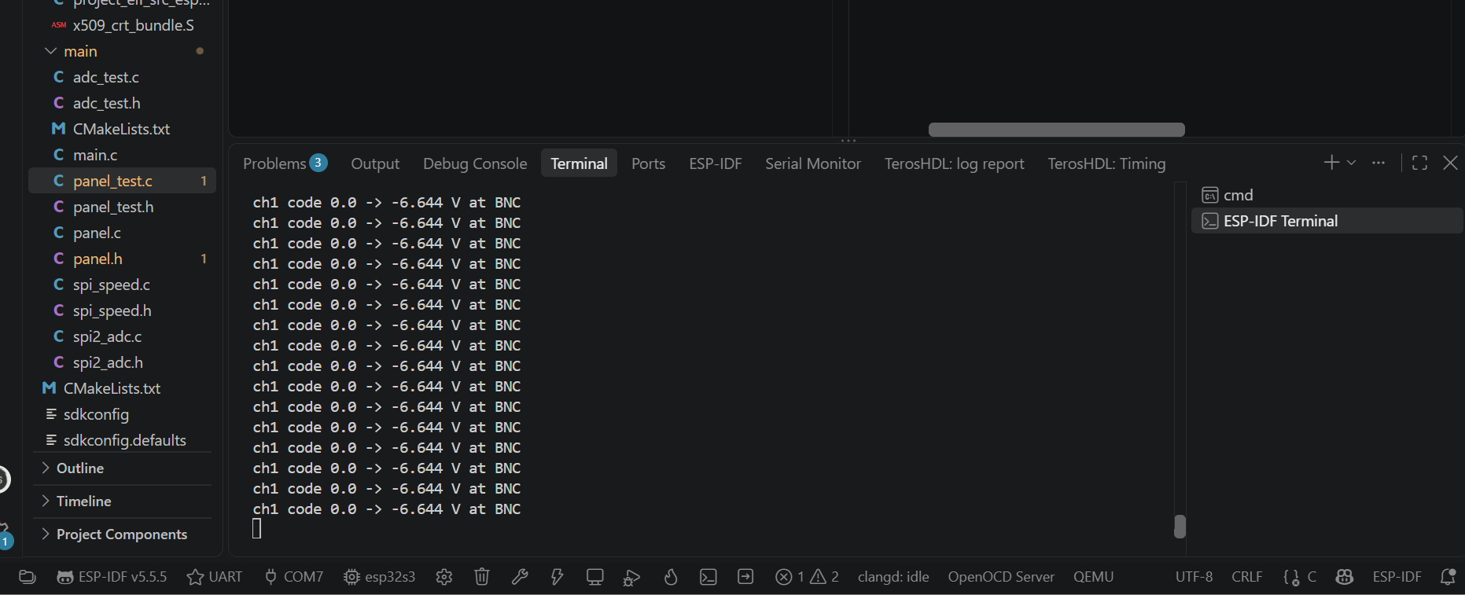
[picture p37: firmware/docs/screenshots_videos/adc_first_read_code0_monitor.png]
Monitor stuck at code 0


Found one: SCLK and CS were swapped on the breadboard. The ADC was being
clocked on its CS pin and selected by the clock, so it never produced a
real frame. With them swapped back the codes move off zero (about 25,
with some frames near 88), so the SPI link is alive. Still well under
the ~2000 expected for 1.63 V in, so VIN is next.

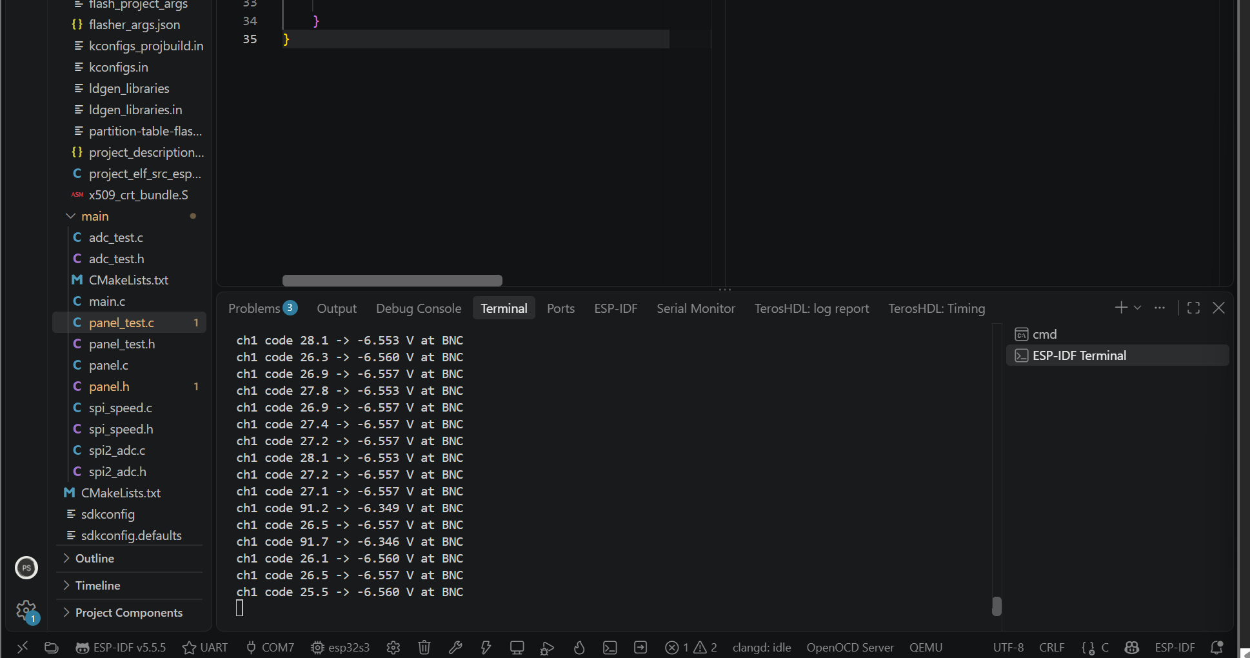
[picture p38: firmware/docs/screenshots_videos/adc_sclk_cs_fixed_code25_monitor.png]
Codes off zero after the SCLK/CS fix


Printed every raw frame instead of the average. About a third of the
frames were wrong, and always the same way: the good code shifted left
one bit (2059 came back as 22). The ADC was one clock ahead, like it
counted an extra SCLK edge right after CS fell.

Put the logic analyzer on it. Two things in the captures: the PulseView
decoder has to match the ADC (mode 0, CS active-low) or it shows garbage
of its own, and the shifted frames were really on the wire. On a bad
frame both SDO lines flick high for about 40 ns after the first falling
edge, then drop, so both chips stepped twice on one edge.

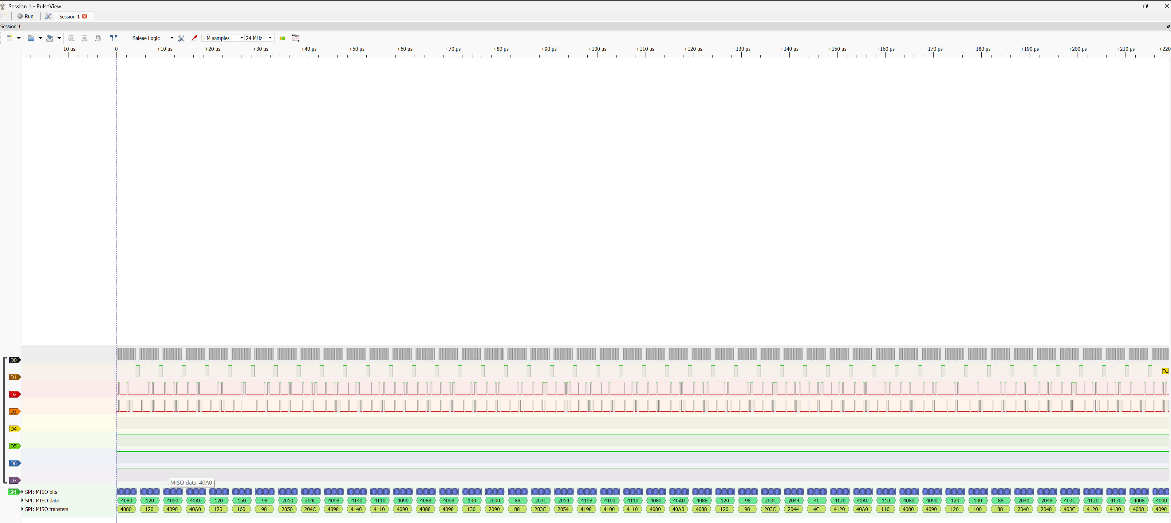
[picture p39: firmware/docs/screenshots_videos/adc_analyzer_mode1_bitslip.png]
Decoder in mode 1: frames shifted


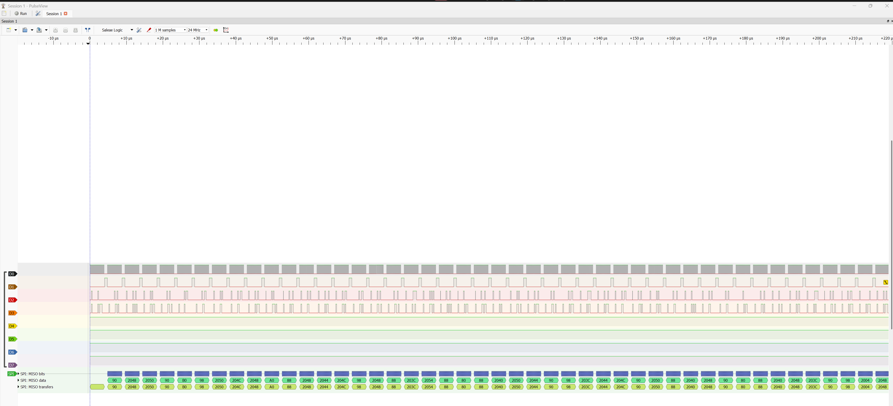
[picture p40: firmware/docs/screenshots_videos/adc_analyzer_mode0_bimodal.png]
Decoder in mode 0: good and shifted frames mixed


Tried, in order:

- SPI mode 1 to mode 0. No real change.
- One clock of CS setup before the first SCLK. Bad frames went from 35%
  to 9%.
- 50R in series with SCLK. Worse, about half the frames bad.
- New jumper, rerouted. Still about 40%.
- Unplugged the logic analyzer. Zero bad frames.

The analyzer was the problem. Its leads on the shared SCLK line plus its
ground going back through USB were enough to make both ADCs double
count a clock edge. The 9% run was the only one taken before it was
clipped on. Lesson: the probe is part of the circuit.

With it off: clean at 4 MHz and at 10 MHz, both channels. Checked CH2 by
moving its SDO wire onto IO13 and touching its input to VREF (code jumps
to about 2720). Kept the CS setup delay, dropped the resistor.

Bench while chasing it

Raw frames at 10 MHz, all good

Last bit was calibration. With IN grounded the ADC reads 2067, which is
1.672 V against a 3.314 V supply, not the 1.661 V I'd assumed. Set the
offset to the measured value and the BNC reading sits at 0.001 V,
steady to one code.

Calibrated: 0.001 V at the BNC with IN grounded

## 2026-09-27

Noise floor at full speed. SCLK at 26.67 MHz, IN grounded, 16384
samples per run, both SPI modes back to back.

Both modes were clean over about 100k samples, no bit-slips, and the
noise is the same: about 4 codes rms, 13 mV at the BNC. Went with mode 1
anyway. At this clock the ADC's data can show up 20 ns after the falling
edge, and mode 0 samples 18.75 ns after it, so mode 0 has negative
worst-case margin on paper. Mode 1 samples a full clock later.

Mode 0 and mode 1 side by side on the monitor

Bench during the noise test

Dumped one run to the PC for a histogram. First try came back with a
third of the lines missing and one corrupted value (061 instead of
2061) that dragged the rms to 19 codes. The board was printing faster
than the USB console could drain. A 10 ms pause every 128 lines fixed
it, and the capture script now rejects anything short or malformed.

Histogram, 16384 samples, IN grounded

Most samples sit within 4 codes of the mean. The rms is pulled up by a
few lone samples 40 to 60 codes out, which looks like pickup on the
breadboard rather than the ADC. The filter as built (165R and 4.4 nF)
puts the corner at about 219 kHz.

The mean at 26.67 MHz is about 2062, 5 codes lower than at 10 MHz, so
the offset calibration has to be done at the speed it runs at.

Both channels in one read. The two ADCs share SCLK and CS, and CH2's
data comes in on the second SPI data line, so one 16-clock frame
brings in 32 bits with the two channels interleaved bit by bit. A
five-step shift-and-mask pulls every other bit back together.

Moved the ADC frame decoding into its own header with no ESP-IDF
includes, so the same code builds on the PC. The host test interleaves
two known words the way the hardware does and checks the fast split
against a plain bit-by-bit loop on 10,000 random pairs.

Host tests passing on the PC

On the board, both inputs grounded at 26.67 MHz: CH1 about 2062, CH2
about 2069. The 7-code gap (about 24 mV at the BNC) is steady, so it's
an offset between the two front ends, and it gets calibrated per
channel. CH1 in the dual read matches CH1 read on its own at the same
speed, so the channels aren't swapped.

Both channels from one frame, inputs grounded

Burst capture with DMA. Until now every sample was the CPU starting an
SPI frame and waiting for it. Now the SPI block and the DMA engine run
a whole burst on their own: a list of 3200 small segments, each one a
full ADC frame, with the gap between frames set by a hardware counter
in 12.5 ns steps. The CPU starts the burst, sleeps, and gets one
interrupt at the end.

To check the timing I needed a signal I trust, so board 1 makes its
own: a 1 kHz square from the LEDC peripheral on a spare pin, jumpered
into CH1's input. Samples per period tells you the real sample rate.

Burst rates on the monitor

100 kSa/s measured 100.26 k, 20 kSa/s measured 20.01 k. The CS-low
part of each segment turned out much longer than the 51 clocks the
math gives, about 124 at the bus clock, because each segment also has
to load its setup from memory. That puts the ceiling at about 620 kSa/s,
not the 1.43 M I'd worked out on paper.

First 3 ms of a burst at 100 kSa/s

The square comes through clean, about 2075 to 3090, with an edge
spread over one or two samples from the front end and the anti-alias
filter.

Reran the noise test with all of this wired up, and this time mode 0
fell apart at 26.67 MHz: minimums down around 20 and 35 to 50 codes
rms, the same bit-slip pattern as before. Mode 1 stayed at about 4
codes. Earlier both modes were clean, so mode 0 was sitting right on
the edge, which is exactly what the timing math said. Glad I went with
mode 1.

Mode 0 slipping, mode 1 clean

Trigger. It scans a capture for the first point where the signal
crosses a level in the chosen direction, so a repeating waveform lands
in the same place every frame instead of sliding across the screen.
Two things make it usable on real signals: hysteresis, where the signal
has to drop clearly below the level before a rising crossing counts, so
noise sitting on the level can't fire it, and a sub-sample position,
interpolated between the two samples on either side of the crossing,
so the trace doesn't jump by a whole sample from frame to frame.

It's pure C, so it's tested on the PC: exact crossing on a clean sine,
a crossing 0.3 samples between two points, chatter at the level ignored,
falling edge, and a noisy sine that still triggers once per period. All
three host test suites pass.

Host tests, trigger added

## 2026-09-28

Decimation. A capture has more samples than the screen has columns, so
each of the 800 columns has to stand for a group of samples. Averaging
or picking one sample per group would make a short glitch vanish. So
each column keeps both the lowest and the highest sample in its group,
and the screen draws a line between them. A spike one sample wide still
shows up.

Also pure C and host-tested: a one-sample spike survives, constant input
stays constant, 800 samples into 800 columns comes out unchanged, and a
ramp whose length isn't a multiple of 800 has every sample land in
exactly one column with no gaps. All four host test suites pass.

Host tests, decimation added

How the trigger and decimation work, drawn out: frames lining up on the
rising edge, hysteresis stopping noise at the level from firing it
again, the crossing placed between two samples, and min/max keeping a
one-sample glitch that averaging would shrink.

Trigger and min/max decimation explained

How capture actually runs. Each burst is one-shot: the CPU starts it,
the DMA fills 3200 samples on its own, the SPI block stops after the
last segment and fires one interrupt. Then the CPU triggers, decimates
and sends the frame, and only then starts the next burst. Whatever the
signal does in between is never recorded. That's dead time, and every
digital scope has it, the spec is called waveform update rate.

Burst coverage, the capture loop, and a damped signal

How much of the signal one burst holds depends on the ratio of signal
frequency to sample rate: cycles = f x 3200 / fs. A 1 kHz sine at
100 kSa/s is 32 cycles, at 620 kSa/s about 5. Frames are never stitched
together, so a one-time event like a damped oscillation has to fit
inside a single burst: slow the sample rate until it does, and use
single-shot so it's captured once and held.

Could the dead time go away? Checked the TRM (30.5.8.5): the segmented
transfer keeps going as long as each segment's CONF sets
usr_conf_nxt = 1, and my last segment clears it on purpose. Loop the
descriptor chains back to the start and set it everywhere, and it
should run as a continuous ring at the same data rate a burst already
proves. The catch is knowing when half the ring is full: the SPI
done interrupt only fires at the end, which never comes, and the GDMA
per-descriptor interrupt would fire on every sample. It would need a
timer or polling. And the screen only shows about 30 frames a second
out of roughly 190 bursts, so it only pays off for something like a
glitch search over every burst. Staying with one-shot for now, the
ring is a later experiment, untested.

Acquisition task. Board 1 now runs on its own: a FreeRTOS task pinned
to core 1 loops capture, trigger, min/max, and builds the frame that
will go to the display board. A settings struct under a mutex holds the
rate, trigger level, edge and source, and RUN/STOP/SINGLE, so the panel
buttons (and later the display board) can change it safely from other
tasks. AUTO mode shows an untriggered frame after three missed bursts,
so a flat line still draws instead of freezing.

Default rate is 320 kSa/s (500 us/div at 1600 samples). 800 kSa/s for
200 us/div was the plan on paper, but it's above the 620 kSa/s I
measured, so at full record length that setting is out.

With the 1 kHz bench signal on CH1: 70 frames/s, every frame triggered,
0 errors, about 2 KB of the task's 4 KB stack left. One burst is
3200 samples at 320 kSa/s, 10 ms, so the ceiling is 100 frames/s, 70
means about 4 ms per frame of trigger, decimation and re-arming the
burst, roughly 30% dead time. RUN stops and restarts with all three
LEDs following, SINGLE captures one frame and holds.

Stats line: 70 frames/s, every frame triggered, no errors

Board 1 running on its own, RUN, TRIG and ARM lit

Link protocol. Board 1 has to send frames to board 2 over a UART, and a
UART only moves bytes: no message boundaries, no error check, no way to
find your place if you start listening mid-stream. Each message is now
type, sequence number, length, payload and a CRC-16, then COBS-encoded
so the byte 0x00 never appears inside it, then a single 0x00 to end it.
The receiver collects bytes until 0x00, decodes and checks the CRC,
after garbage it just waits for the next 0x00 and is back in sync. A
jump in sequence number counts as a lost frame. Pure C, host-tested: the
published CRC check value, COBS at its awkward lengths (253, 254, 255),
a flipped bit caught, garbage ignored, a missing frame counted.

UART driver, written from the registers: UART1 on GPIO43/44 through the
GPIO matrix, an interrupt handler and a ring buffer each way. Tested in
loopback, a 220R from TX back to RX on board 1, sending frames of random
length up to 7 KB at 2 Mbaud. 15,600 frames in about 4.5 minutes, every
one intact, zero CRC, length, framing, overflow or dropped-byte errors.
About 55 frames a second of 3.6 KB average, so the wire is running at
full speed. The ring buffer is host-tested too, and all six host test
suites pass.

Six host test suites passing

UART loopback: 15,600 frames at 2 Mbaud, no errors

Loopback on the bench, LINK1 pins on the schematic

Board 1 to board 2. The two boards are now wired to each other: each
TX through a 220R to the other's RX, grounds joined. Board 1 sends every
decimated frame (a 64-byte header plus min and max for both channels,
6.5 KB) and every panel event, board 2 sends pings and settings back,
and board 1 answers settings with its run state and actual sample rate.
One shared header defines every message so all three boards agree.

About 31.8 frames/s arrive, which is what 2 Mbaud allows for 6.5 KB
frames, with zero CRC, length or dropped-byte errors. Every encoder
turn, press and release shows up on board 2. RUN reports STOP, SINGLE
reports SINGLE then STOP after one frame, and a settings change from
board 2 comes back confirmed. Ping round trip is about 40 ms because a
ping waits behind a frame that takes 33 ms to send.

The COBS and framing errors in the screenshot are from unplugging. With
one board unpowered, the other kept driving its RX pin, which back-powers
the dead chip through its pin, it then came up with a stuck USB port
until reset. The counts stay flat while both run, so no new errors. The
220R resistors are there to keep that current small. Rule for the bench:
power both boards together, or reset the one plugged in last.

Both monitors: frames, keys and state messages

Board 1 and board 2 on the bench, crossed LINK1

[Video: LEDs and keys with the link running](firmware/docs/screenshots_videos/link1_leds_keys_demo.MP4)

Display prep. Soldered header pins onto the four display boards: the
Adafruit 40-pin TFT breakout for the panel ribbon, the 6-pin FPC
adapter for the touch ribbon, the XL6009 boost for the backlight and
the 5 V input. Beeped every pad against its neighbour for shorts and
against the pin it should reach. All clean.

Mapped the breakout against Adafruit's schematic before wiring anything.
The silkscreen matches this panel's RGB, clock, sync, DE and DISP pins,
but three things differ. The breakout ties ribbon pins 3 and 36 to
ground and leaves 35 open, on this panel those are the SPI chip select,
data and clock, so the panel runs its default RGB mode and the CS/SPI
tie-offs on my schematic are left out. The LA pad has a 24 V clamp
diode across the LED string for the breakout's own driver, this
backlight needs 25.6 V, so the diode comes off before the XL6009 drives
it. And 5VIN powers the breakout's boost chip, so it stays unconnected.

First fit the ribbon went in flipped and every pin came out mirrored
(pin 1 on YU). Caught it with the meter before powering anything.

Parts laid out before soldering

Breakouts soldered, continuity and short check

Backlight, alone. Set the XL6009 with nothing on its output first: it
turns down to about 5 V (a boost can't go below its input) and up past
22 V, so the module regulates. Parked it at 20 V, below where the LED
string turns on. Then wired OUT+ through a 100R to LA and LK to ground,
and crept the trimpot up with the meter across the resistor.

Almost no current at first, then it came up fast once the string
turned on, the knee 8 LEDs in series predict. At 25.5 V out it was
3.0 V across the 100R (30 mA). Stopped at 4.0 V across the 100R:
40 mA, two thirds of the rated 60 mA and well under the 75 mA maximum.
The booster reads 27 V, so the string drops about 23 V. Used 100R
instead of the schematic's 75R (the resistor kit has no 75R), it
dissipates 0.16 W at 40 mA, inside its rating.

The breakout's own 24 V clamp sits across the string. At 23 V it stays
below its threshold, and after a minute everything on the breakout was
cool, so it stayed on the board. Nothing else of the panel is connected
yet, so the glow is plain white.

Backlight lit at 40 mA from the XL6009

Colour bars, first attempt. Before wiring, reordered board 2's LCD pins
so the left header runs in the breakout's pad order: reds, then all five
blues, then all six greens, then the pixel clock. The LCD peripheral
reaches its pins through the GPIO matrix, so any free pin can carry any
bit, same 27 GPIOs, only the labels and the pin header changed. Wired
the 16 data lines, clock, HSYNC, VSYNC and DE, tied the unused low bits
(R0 to R2, G0, G1, B0 to B2) to ground and ON/OFF high through 10k. The
breakout already grounds the panel's SPI chip select and data pins, so
the CS/SPI tie-offs on my schematic have nowhere to go and are left
out. Touch ribbon wired too, with 2k pull-ups on SCL and SDA for margin.

The firmware side is up: the panel driver starts at 800 x 480, 16 MHz
pixel clock, 32.8 Hz refresh, and the test cycles bars, bits and border.
The panel stays plain white, which is what it shows with backlight but
no working logic. Next: DC-check the 3.3V, GND, ON/OFF, CLK (should
average about half the rail), HSYNC, VSYNC and DE pads, and reseat the
ribbon.

First bring-up: test running, panel still white

What it should show, drawn from the test code: colour bars, then one band
per data wire (dim to bright blue, green, red), then a 1-pixel border.

Expected test patterns

## 2026-09-29

Colour bars, fixed. The white screen was power, not signals. The panel's
3.3 V read 2.3 V off the breadboard supply, below its 2.7 V minimum, and
the supply's parts ran hot. Moving the panel to board 2's own 3.3 V (as
the schematic has it) dragged that rail to 2.2 V too, so something on
the breakout was loading it.

Adafruit's schematic explains it. The breakout's 3.3V pad is the output
of its own small regulator, whose input is 5VIN. Feeding 3.3 V into that
pad leaks back through the regulator onto 5VIN, and 5VIN also powers
the breakout's backlight boost chip, whose enable pin (PWM) is pulled up
to 5VIN. So the boost chip switched itself on and pulled hard on my
3.3 V rail. Tied PWM to ground to hold it in shutdown, left 5VIN
unconnected, and the rail holds at 3.3 V.

Now the panel's logic, touch, pull-ups and ON/OFF all run from board 2's
3.3 V, so the panel switches on and off with the board, and the backlight
stays on its own 5 V through the XL6009. Colour bars come up, and the
test cycles through the bit bands and the border.

Colour bars on the panel

RGB bus wiring into the breakout

[Video: test patterns cycling](firmware/docs/screenshots_videos/lcd_test_patterns_running.MP4)

Touch controller answers. A throwaway I2C scan on board 2 found the
GT911 at 0x14 (it picks 0x14 or 0x5D from the INT level at reset, which
the scan left floating), and a short poll read its product ID back as
"911" and printed X/Y as I dragged a finger around. Test code reverted,
the real driver comes later and will drive INT to pin the address.

Generator next. The resistors arrived, so the R-2R ladder goes on board
3 tonight. Changed the ladder to use one value only: every 2R leg is a
single 10k and every R is two 10k in parallel (5k), 23 parts. The ratio
is what sets linearity, and same-value parts hold 2:1 by construction,
parallel pairs also sit in one pair of breadboard rows where series
pairs need a middle row each. Tolerance math for 1% parts gives about
0.5 LSB typical at the mid-scale carry, so I'll meter the 10ks and put
the closest ones at the D7/D6 end. Ladder output drops from 10k to 5k,
which moves the Sallen-Key filter from 23 kHz (Q 0.73) to 33 kHz
(Q 0.69) with R38 left at 10k. Still flat, just a slightly higher
corner.

Bench set up for the ladder

## 2026-09-30

Ladder bit weights. Each bit set alone, measured at the ladder output
(the R38 row) against board 3's 3V3 pin, 3.288 V. Expected is
3.288 x code / 256. Meter zero offset of 0.7 mV subtracted.

| Code | Bit | Expected | Measured | Error |
|---|---|---|---|---|
| 0 | none | 0 | 0.7 mV | meter offset |
| 1 | D0 | 12.8 mV | 12.7 mV | -1% |
| 2 | D1 | 25.7 mV | 25.7 mV | 0% |
| 4 | D2 | 51.4 mV | 51.5 mV | +0.2% |
| 8 | D3 | 102.8 mV | 102.9 mV | +0.1% |
| 16 | D4 | 205.5 mV | 205.2 mV | -0.1% |
| 32 | D5 | 411.0 mV | 409.7 mV | -0.3% |
| 64 | D6 | 822.0 mV | 817.3 mV | -0.6% |
| 128 | D7 | 1.644 V | 1.651 V | +0.4% |
| 255 | all | 3.275 V | 3.271 V | -0.1% |

Every bit within 1% on 1% parts, with the all-10k ladder (2R single,
R as parallel pairs). The MSB is 0.4% high, about half an LSB at the
127 to 128 carry, so the output stays monotonic.

Two traps on the way. First reading at code 255 was 2.2 V, which was
the D0 node, not the output: with all bits high, the node next to the
terminator sits at 2/3 of the rail, and a quick nodal solve matched it
to the millivolt. Then the single bits read almost zero while 128 and
255 read the full rail, because I was probing the top of R37, which is
GPIO11 itself. The output is the bottom of R37, the row R38 starts in.

Also found board 3's 3V3 at 2.9 V on USB. Not the board: the USB hub
was also charging my phone and its 5 V sagged. Unplugged the phone and
the rail came back to 3.288 V.

Ladder built beside the generator sheet

Bit test running, code 0 at the ladder output

Ladder staircase. Swapped the bit test for the ramp: codes 0 to 255,
20 us each, on repeat. On the scope at the ladder output it's a clean
sawtooth, 0 to 3.28 V by cursor, repeating every 5.44 ms. That's a bit
longer than the ideal 5.12 ms (256 x 20 us) because each code also pays
for the loop and the store, and every 64th ramp yields a tick to the
idle task, so about 21 us per code in practice. At 2 ms/div the 12.8 mV
steps are too fine to see, which is expected, the bit-weight table
above already puts the 127 to 128 step within half an LSB.

Staircase on the scope, cursors on one ramp

[Video: staircase running](firmware/docs/screenshots_videos/gen_r2r_staircase_running.MP4)

Waveforms from a timer interrupt. A 32-bit phase accumulator adds a
tuning word every sample, and the top 8 bits pick the next code: from a
256-entry sine table, a compare for square, the index itself for saw,
folded for triangle. f_out = tw x 100 kHz / 2^32, so 1 kHz is
tw = 42,949,673 and the step is about 23 uHz. The math is pure C and
host-tested first: tuning word, 1234 Hz counted over 10 s to +-1 cycle,
10% duty, range limits, table landmarks. All seven host suites pass.

On the board it runs in a 100 kHz Timer Group 0 interrupt on core 1,
set up from the registers. The ISR acknowledges, re-arms, then does one
DDS step and one GPIO_OUT store. Everything it touches lives in IRAM or
RAM: the sine table isn't const (a const table lands in flash), and the
shape select is if/else, not a switch that GCC could turn into a jump
table in flash.

Checked at the ladder output: sine, square 50% and 10%, saw and
triangle at 1 kHz, sine at 100 Hz, 5, 10 and 20 kHz. At 10 kHz a sine
is only ten steps per cycle, which is the limit the filter has to work
with. ISR execution time on the timing pin not measured yet.

Sine, 1 kHz, unfiltered

Square, 1 kHz

Saw, 1 kHz

Triangle, 1 kHz

Seven host test suites passing, DDS added

LVGL on the panel. The display now draws through LVGL 9.3 and
esp_lvgl_port instead of filling the framebuffer by hand. Two PSRAM
framebuffers with tearing avoidance (LVGL draws one while the panel shows
the other), and 10-line bounce buffers in internal RAM so the LCD DMA
never waits on PSRAM. LVGL renders on core 1, the RGB refill interrupt
stays on core 0. First screen is plain: the default light theme, "Oscil"
centred, and LVGL's FPS/CPU monitor in the corner. Held still for a
minute with no drift or tearing.

Two snags. The build failed first: the manual pinned LVGL 9.2 but the
newest esp_lvgl_port 2.x uses a colour format added in 9.3, so the
manifest now allows LVGL 9.3. Then the grey text and the monitor box came
out purple. The bit-line test showed why: black was maroon, and the last
band (R7 alone) matched the background, so R7 was stuck high. The
jumpers on that side of board 2 had shifted two rows, putting R5 and
below on the wrong header pins, one of them 3V3. Moved them back and
black is black again.

LVGL hello screen

RGB bus wiring, panel flipped

[Video: LVGL hello screen running](firmware/docs/screenshots_videos/lvgl_hello_running.MP4)

Touch. The GT911 now runs through Espressif's esp_lcd_touch driver and
feeds LVGL as an input device. At reset the driver holds INT low, which
makes the chip answer at 0x5D instead of the 0x14 the earlier throwaway
scan found, the boot scan sees exactly one device at 0x5D and reads the
product ID back as "911". A red dot follows the finger and every press
prints its coordinates. X and Y come out in the right directions, no
mirroring or swap needed.

Touch coordinates in the monitor

[Video: dot following the finger](firmware/docs/screenshots_videos/touch_dot_following_finger.MP4)

Scope view, first try (not working yet). Board 2's links moved into their
own module, and a scope view draws the min/max frames from board 1 onto
an 800x400 plot: a graticule drawn once and copied each frame, one
vertical run per column from min to max, CH1 yellow and CH2 cyan, and
two frame slots between the link task and the renderer so a slow draw
drops old frames instead of tearing. Screen comes up with the plot and
the grid, but no trace.

The LINK line says why: about 1 frame/s gets through instead of the 30
board 1 sends, and the CRC, COBS and length counters climb fast. FIFO
overflows, ring drops and framing errors all stay at 0, so board 2 keeps
up and the baud matches, the bytes are arriving with bits flipped. Since
the board 1 to 2 test passed at 31.8 frames/s before the
display was running, this points at the wiring rather than the code:
the 16 MHz pixel clock and 16 data lines now switch next to the link
wires, and the grounds run through long breadboard jumpers.

Along the way the bench 5 V sagged to 4.1 V under load. The backlight
boost draws about 260 mA, and the breadboard module makes 5 V from 9 V
with a small linear regulator that has to burn 4 V x 0.3 A, about
1.2 W. Moved the XL6009 to its own bench supply at 5.0 V, the module
now only feeds the front end and holds 5 V.

Next: short ground between boards 1 and 2 beside the link wires, link
wires routed away from the display bundle, and 1 Mbaud as a fallback.

What it should look like:

Expected scope view (illustration)

What it does today:

Scope view, grid only, link corrupting frames

[Video: scope view first try](firmware/docs/screenshots_videos/scope_view_first_try.MOV)

## 2026-10-01

Scope view, live. Board 1's frames now draw on board 2's screen: the
1 kHz test square on CH1 over the graticule, the link at 31.8 frames/s
with zero errors. Getting there took a day of isolation tests, because
the failure only showed up with everything running.

The symptom: about 1 good message per second, CRC, length and COBS
errors climbing, a grid with no trace. Each piece was added back alone,
one flash per test: link only, then the panel, LVGL, touch, and the
scope view with no frames fed to it. All clean at 31.8/s. Connecting the
frame callback broke it again, and leaving the drawing task asleep while
still receiving and copying frames made it clean. So the trigger was the
drawing, not the wiring.

Drawing alone exposed the real counter: ovf, the UART's hardware RX FIFO
overflowing. Each frame the scope task copies a 640 KB background in
PSRAM and redraws the traces, about 34 ms of heavy memory traffic, and
the UART interrupt on core 0 couldn't always empty the 128-byte FIFO in
time. Four changes fixed it:

- UART interrupt raised to level 3 so it runs ahead of the display's.
- RX FIFO threshold from 64 to 32 bytes: more headroom before overflow.
- On overflow, reset the RX FIFO instead of only counting it. Before
  this, one overflow left the receiver broken for good, now it costs a
  frame and the decoder resyncs on the next delimiter.
- A 10 ms pause after each draw, so core 1's idle task runs (the task
  watchdog was firing) and PSRAM gets a gap. ovf stayed at 0 after this.

Then a crash on re-enabling the measurement labels: LVGL's built-in
printf doesn't do %f, lost its place in the argument list and read a
float as a string pointer (NULL). Formatting with the C library's
snprintf first fixed it.

Where it stands: stable, 8 frames/s on screen with the full canvas
redraw (target 25+), and the trace is live but not clean yet, with
gaps in the highs. The captured data from board 1 was a clean 50% square
when dumped earlier, so the next look is board 2's drawing path, along
with only redrawing what changed to get the frame rate up.

Before the fix, link errors climbing while frames draw:

LINK errors while drawing

After the fix, link clean at 31.8/s with the scope drawing:

LINK clean while drawing

First trace on screen, with the gaps in the highs:

First live trace

The scope view running on the bench, board 1's 1 kHz square on CH1:

Live scope view on the bench

Measurements. Board 1 now measures each channel from the full
1600-sample record, before decimation, and sends the results in the
frame header: min, max, peak to peak, average, true RMS (DC included),
frequency and duty. Board 2 only displays them. Average and RMS come
from one pass with double accumulators, frequency reuses the trigger:
every rising crossing of the midpoint (10% hysteresis) across the
record, first to last with the sub-sample fractions, over the achieved
sample rate. Duty is the share of samples above the midpoint. Host
tested first: DC, sine RMS, a 1 kHz sine within 0.1%, a 25% square.
Eight host suites pass.

On the 1 kHz test square, nominal calibration:

| Measurement | Oscil | Expected |
|---|---|---|
| Frequency | 996.0 Hz | 1000 Hz |
| Duty | 50.0% | 50% |
| Average | 1.749 V | midway between the levels |
| RMS | 2.431 V | high level / sqrt(2) |
| Min / max | -0.235 / 3.590 V | levels about -0.13 / 3.45 V, plus noise |
| Peak to peak | 3.825 V | max - min |

The level offsets are the nominal calibration, the real one comes later.
The link stays at 31.8 frames/s with zero errors and board 1 still
captures 31 frames/s with the measuring added.

Measurement panel on the 1 kHz square

Bench with measurements running

Host tests, measurements added

Link clean, board 1 measuring

[Video: measurements running](firmware/docs/screenshots_videos/measure_running.MP4)

## 2026-10-02

Controls. Board 2 now owns every user setting in one struct, and every
input goes through one function: the knobs and buttons on board 1 arrive
as key messages, the touch buttons call it directly, and both change the
same settings. Board 1 only reports turns and presses, it no longer
toggles RUN or SINGLE itself (a compile-time switch keeps that for
running board 1 alone), so a press can't toggle twice. Changes go out
only to the board that needs them: timebase and trigger to board 1,
V/div and channel on/off stay on the display. At startup board 2 pushes
its settings to board 1, so after a display reset both agree. Keys from
the link task reach the UI through a queue, so the link never waits on
the display lock.

Knob map: ENC1 timebase, ENC2 V/div of the selected channel (push swaps
channel), ENC3 trigger level (push flips the edge). Top bar: RUN/STOP,
SINGLE, CH1, CH2, TRIG, MEAS, PHOS, GEN, SAVE. The status bar shows
timebase, both channels' V/div, and the trigger source, edge, level and
mode.

Two problems on the way:

- Boot loop: the status bar was formatted with LVGL's own printf, which
  has no float support. The trigger voltage shifted the arguments and the
  last string pointer was garbage. Formatted with libc snprintf instead,
  the same fix as the measurement labels.
- In STOP the trace ignored V/div, because the canvas only redrew when a
  new frame arrived. A view change now redraws the last frame. Timebase
  and trigger still apply on the next capture: board 1 sends decimated
  columns, so a stopped trace can be rescaled vertically but not in time.

In STOP the link drops to the ping and state messages (0.9 messages/s)
and comes back to 31.8 frames/s with zero errors on RUN.

Stopped, status bar showing the settings

Link in STOP and RUN, board 1 still capturing on demand

[Video: knobs and touch driving the scope](firmware/docs/screenshots_videos/controls_knobs_and_touch.MOV)

Generator screen. A second LVGL screen for the generator: shape buttons,
frequency (tap for a numeric keypad), amplitude and offset sliders, a
duty slider shown only for square, output on/off, and a one-period
preview. Every widget calls the same action function as the knobs, and
that function refreshes the screen after every generator change, so
touch and knobs follow each other both ways without loops (LVGL setters
send no events). Amplitude and offset are the DDS's own lo/hi codes,
clamped so neither leaves 0..255. The preview is drawn by dds_next(), the
same code board 3 runs in its timer interrupt, so the picture can't
disagree with the output. Board 2 sends the settings on LINK2 every
500 ms, board 3 starts following once its receiver is in.

Generator screen, 250 Hz sine with the preview

LINK2. Board 3 now listens. LINK2 is one-way, so board 3 can't
acknowledge anything, instead board 2 sends the whole generator state
right after every change and again every 500 ms, and board 3 applies
whatever arrives. A lost frame is corrected within half a second, and
receiving the same state twice changes nothing. Board 3 flashes its LED
white per frame, then green for output on or dim red for off, and logs
each change plus a status line every 5 s (frames received, time since
the last one, or a warning if the link goes quiet). Frames arrive about
every 500 ms with no gaps.

The generator screen also got easier to read: frequency is a button
that opens the keypad, each slider shows its value (Vpp, V, %), the
switch is labelled, and an output card at the bottom summarises the
setting ("1 kHz Sine, 0.00 to 3.30 V, output on"). All float text goes
through snprintf.

Three boards: generator screen, board 3 following

Board 3 log: frames every 500 ms, the applied setting

Settings and calibration. Board 2 now saves its settings (timebase,
V/div, trigger, channels, generator) to NVS two seconds after the last
change, with a version number and a CRC, and restores them at boot. A
burst of knob turns is one flash write, not dozens.

Board 1 has a two-point calibration per channel, stored in its own NVS
and sent to board 2 at boot. The procedure: input to GND (zero), then
input to the 3.3 V analog rail measured with a DMM (span), averaging
4096 samples each. The inputs are the top of the 750k divider resistors,
the same node the BNC centre goes to.

| Channel | Zero (codes) | Span (codes) | Gain | Offset |
|---|---|---|---|---|
| CH1 | 2067.2 | 3092.9 | 3.9442 | 1.6725 V |
| CH2 | 2074.0 | 3098.6 | 3.9481 | 1.6781 V |

Span source 3.273 V. Nominal was gain 4.0 and offset 1.65 V, about 1.4 %
and 25 mV off, which is what had the step 36 levels reading wrong. After
calibration the 1 kHz test square reads min -0.106 V, max 3.526 V,
avg 1.735 V, 996.0 Hz, 50.0 % duty (min/max include the trace noise).

It took four runs. The first ran with the sampler still active, so two
tasks drove the ADC bus at once. The second used a span value taken while
the analog rail was sagging. The third had CH2 reading the same code
(about 2763, the 2.2 V reference level) whatever the input: the jumper
wasn't in the R7 row, so the divider input was floating. The fourth was
clean, and the two channels agree within 0.1 %.

Spikes after rewiring. For a while both channels showed single samples
jumping to the edge of the screen. Every bad sample was off by exactly
2048 codes, the ADC's most significant bit, so it was a bit error on the
SPI read, not analog noise. Slowing SCLK from 26.67 to 20 MHz made it
worse (the sampler's timing is built around 26.67 MHz) and was reverted.
The spikes then stopped with the original code after the jumpers were
re-seated, so the cause was a marginal connection. If they come back:
press on the SCLK, CS and SDO jumpers while watching, and the CS setup
time (one clock now) is the first margin to add.

Calibration on the bench: DMM on the span source

Calibration results on the monitor

1 kHz square after calibration

Small display changes. Minor ticks on the scope's centre axes, five per
division, so a level can be read to a fifth of a division. A faint 4 x 4
grid in the generator preview, so amplitude and offset show where the
wave sits in the 0 to 3.3 V range. The generator output now always
starts off at power-up, whatever was saved, shape, frequency, amplitude
and offset are still restored.

Scope with minor ticks, calibrated 1 kHz square

Generator preview with its grid

Partition table. All three boards now use the same 16 MB layout:

| Partition | Offset | Size |
|---|---|---|
| nvs | 0x9000 | 24 KB |
| otadata | 0xF000 | 8 KB |
| phy_init | 0x11000 | 4 KB |
| ota_0 | 0x20000 | 4 MB |
| ota_1 | 0x420000 | 4 MB |
| storage (LittleFS) | 0x820000 | 7.9 MB |

Two app slots so an update can be written to the slot that isn't running
and rolled back if it fails, app rollback is on in the bootloader. NVS
kept its offset and size, so board 2's settings and board 1's
calibration survived. The images are far below a slot: board 1 about
241 KB, board 2 about 654 KB, board 3 about 213 KB.

The first build ignored the new settings: sdkconfig.defaults is only read
when no sdkconfig exists, and each board already had one. Set the custom
table and rollback in menuconfig on each board, and kept the lines in
sdkconfig.defaults so a fresh clone builds the same way.

All three boards building with the 16 MB table

## 2026-10-03

Board 2 joins Wi-Fi as a station. Everything is event-driven: the
driver reports start, disconnect and got-IP as events, and other tasks
wait on one event-group bit (online) instead of polling. A dropped
connection retries with exponential backoff, 1, 2, 4, 8, 16, 32 s up to
60 s, from a one-shot FreeRTOS timer, so a rebooting router isn't
hammered. SNTP starts once on the first IP so captures get real times.
Credentials are compiled in from a git-ignored secrets.h, provisioning on
the device is future work.

The ESP32-S3 radio is 2.4 GHz only and the home network is 5 GHz, so it
runs on a phone hotspot with its 2.4 GHz compatibility mode on. First
attempts showed the backoff working but never connecting, on the hotspot
it joined on channel 6, WPA2, RSSI -39 dBm, and got 172.20.10.6 by DHCP.
The scope and LINK1 kept running throughout: 31.8 frames/s, no errors.

Backoff while the network is unavailable

Connected to the hotspot

OTA. Board 2 now updates from SYS, using the display binary on the
latest GitHub Release. HTTPS checks the server certificate against
ESP-IDF's bundled roots, writes the other app slot, verifies the image
and sets it for the next boot. SYS shows the firmware version, Wi-Fi
state and RSSI, free and minimum heap, and the scope frame rate.

The first attempts reset while writing flash with the display running.
One watchdog reset stopped in the panic handler, later runs caught
illegal instruction and instruction-fetch errors. Pausing the scope
task, then holding the LVGL lock for the download, did not make it
reliable. The lock also held up UI callbacks from the link receiver,
so incoming bytes were dropped. An update with the LCD left unstarted
completed. That narrowed the problem to the display setup alongside
OTA, but did not identify the exact cause. The panic handler is now in
IRAM so failures during flash operations can be reported.

The update button now saves a one-time request in NVS and reboots.
Before starting the LCD, touch or LVGL, the next boot consumes the
request and starts an OTA task. It waits up to 30 s for Wi-Fi, downloads
with the screen disabled, then reboots. LINK1 keeps draining frames
without UI callbacks. A failed attempt returns to normal startup, the
request is already cleared, so another reset cannot start an update
loop.

Tested from 0.8.0 to 0.8.1, starting with the touchscreen button. The
download took about 26 s after entering update mode, the new image
booted from ota_1 at 0x420000, and the self-test confirmed it. The test
checks the LCD, touch and a recent frame from board 1, allowing up to
5 s for that frame. The screen returned and LINK1 stayed at about
31.8 frames/s with zero errors during the download and after reboot.

```text
ota: update requested, rebooting without LCD
ota: update mode: LCD, touch and UI disabled
ota: done, rebooting
App version: 0.8.1
ota: 0.8.1 is new: self-test
ota: new image confirmed
```

Update mode, certificate checks and the download starting

0.8.1 confirmed, scope running and LINK1 clean

[Video: touchscreen update from 0.8.0 to 0.8.1](firmware/docs/screenshots_videos/ota_update_0_8_0_to_0_8_1.MP4)

Accounts on board 2. Added the Supabase HTTPS client and account session
code. Requests use the bundled certificate roots and the publishable key,
user requests carry the access token. The refresh token, username and user
id are saved in NVS. The access token stays in RAM and is renewed when
needed, including after reboot.

Tested sign-in as `paul_test`. TLS validated, sign-in returned ESP_OK and
the token was 800 characters. After a reset, the test printed "session from
NVS: paul_test" and obtained a token again without another password login.
Forced sign-out for the negative test, then supplied a wrong password.
It returned "Wrong username or password" with ESP_FAIL and no valid token.

LINK1 stayed at 31.8 frames/s in the sign-in run. The reset run recorded
one length error, 44 gaps and 281726 dropped bytes at startup, those counters
stayed flat in the following logs and reception returned to 31.8 frames/s.
The cause of that startup disturbance is not established. The scope drew
at about 4.7 fps, around 203 ms per frame, slower than the earlier run.

Device sign-in succeeded

Session restored after reset

Wrong password rejected, no token issued

Account screen. SYS now opens a page with Sign in, Create account and
Forgot password modes, a text keyboard, account status, Sign out and Back.
Password fields are masked. Create account asks for a secret phrase, reset
asks for that phrase and a new password. Network requests are queued to a
worker task so the LVGL task does not wait on HTTPS.

The manual's SYS replacement called the old OTA function. Kept the working
NVS request and reboot updater, so adding Account does not restore the
update path that failed with the LCD running.

The first touchscreen sign-in validated the certificate, then failed with
"esp-aes: Failed to allocate memory" and a TLS read error. The hardware AES
path needs temporary DMA-capable buffers, its allocation failed. Disabled
hardware AES in menuconfig and saved the same setting in sdkconfig.defaults.
TLS now uses software AES, with certificate checking still enabled. Account
operations worked after this change. Exhaustion versus fragmentation of
the DMA heap was not measured.

Recorded the three account screens, button navigation, password reset and
sign-in with the new password. Captures are kept with the firmware evidence,
the Supabase setup and PC isolation test stay under software.

Account sign-in screen

Create account screen

Forgot password screen

[Video: account screen buttons](firmware/docs/screenshots_videos/account_screen_buttons.MP4)

[Video: account screen navigation](firmware/docs/screenshots_videos/account_screen_navigation.MP4)

[Video: forgot password test](firmware/docs/screenshots_videos/account_forgot_password_test.MP4)

[Video: password reset and sign-in with the new password](firmware/docs/screenshots_videos/account_reset_new_password_sign_in.MP4)

Cloud photos. SAVE now takes a screenshot of the scope screen into RAM
and uploads it directly to the signed-in user's private Supabase folder.
The earlier file uploader expected a locally saved .osc capture, replaced
that path with an LVGL snapshot and BMP upload. No photo is written to
LittleFS. NVS keeps a screenshot counter across normal reboots.

The RGB565 snapshot is streamed as a 24-bit BMP, one converted row at a
time. An 800 x 480 image is 1,152,054 bytes. Raised the screenshots bucket
limit from 64 KB to 2 MB and saved the new limit in software/schema.sql.
The bucket remains private, with the existing owner policies.

Snapshot capture briefly takes the LVGL lock. The upload and metadata row
run on a worker task, a second SAVE while it is active reports "Photo
upload busy". Closing the request frees the snapshot. Signed-out SAVE is
refused. HTTP header and body read failures now return an error instead
of reporting a successful request.

The display rebuild compiled and linked, and the binary passed its app
partition size check with 65% free. Device testing passed: signed-out
SAVE showed "Sign in to save photos", repeated presses during uploading
showed "Photo upload busy", and a completed upload showed "Photo saved
to your account". Recorded the SAVE sequence and the resulting image in
Supabase.

The Account screen photo list and viewer are next. They are not part of
this change. The planned viewer will fetch only a selected photo into
RAM and free it when closed.

SAVE refused while signed out

Repeated SAVE presses while uploading

Photo saved to the signed-in account

[Video: cloud SAVE, busy guard and the Supabase image](firmware/docs/screenshots_videos/cloud_photo_save_busy_supabase.MOV)

### Photo viewer and selected trace touch

Added My photos to the signed-in Account screen. The gallery lists 20
metadata rows per page, newest first, it does not download thumbnails.
Tapping a row fetches that photo with the user's access token. The BMP is
read a row at a time and converted into one RGB565 PSRAM buffer, at most
768 KB. Close frees it and returns to the list. Leaving while a request is
running cancels its result, so an old download cannot reopen a photo.
The bucket and owner policies are unchanged.

Kept the scope layout and changed the top buttons to a dark background,
with a yellow or cyan border around the selected channel. Holding near
that trace for 300 ms starts dragging. Vertical movement changes only
that channel's voltage offset, horizontal movement pans only its display.
It does not change the sample rate or acquisition trigger position. ENC1
press centres it again. ENC3 and TRIG use the selected channel as source.
The persisted settings structure has not changed, horizontal pan starts
at zero after reboot. SAVE is refused away from the scope screen.

The display compiled and linked. Seven host tests passed for BMP headers,
both row directions, padding, RGB565 colours and malformed input.

Photo viewer startup correction. The first device attempt reported
"Photo viewer unavailable" before opening the gallery. That message came
from queue or worker creation, before any Supabase request. The worker
asked for a 12 KB internal stack, moved it to PSRAM and made the queue and
task control blocks static so startup no longer needs that internal heap
allocation. Kept PSRAM XIP enabled because token renewal can write NVS.
Added startup heap diagnostics and a "worker ready" log.

## 2026-10-04

### Gallery review

Rechecked the PSRAM worker stack, static queue/task controls, token use,
private folder paths, image bounds and cleanup when leaving a request.
The nine host suites passed, including the seven BMP cases. Corrected an
offline pagination case: Next, Previous and Refresh now keep the current
page when no request can start. Made gallery JSON parsing strict and
added HTTP/stage logs for a failed list or photo download. Photo requests
use the same 2 KB HTTP buffers as the uploader.

The signed-out guard and RAM-only photo path remain in place. Trace pan
is limited to the selected channel, with bounded horizontal positions,
ENC1 resets both offsets and trigger controls use the selected source.
A saved STOP state can still boot to an empty grid because waveform data
is not persisted. RUN with AUTO is the first check in that situation.

### Photo viewer on the device

Opened a saved cloud photo in the device viewer. The new capture shows
"Photo 4" with the saved scope image, both channel traces, measurements
and the Close control. This confirms gallery startup and a selected photo
being displayed after the worker startup correction.

Saved cloud photo open on the device

### Touch failure during sign-in

The display rebooted after a GT911 I2C timeout. The backtrace reached
LVGL's fatal touch-read check, it did not show an Auth rejection.
Added a project-side adapter that releases touch on an error, logs the
failure and lets the next read retry. Reduced the touch bus to 100 kHz
for the breadboard harness. Downloaded components are unchanged.

Moved the account worker's 12 KB stack into PSRAM with the same XIP
requirement as the gallery. Queue and task creation are checked, failed
submissions clear Working and show an error. Added request start/finish
logs without passwords, phrases or tokens.

### Photo numbering after the board swap

The replacement display started at photo 1 while the account still held
photos from the old board. Before allocating a number, the uploader now
reads the account's highest shot_id and keeps the larger of that next
number and the local counter. Existing photos are never overwritten.

Storage errors now include the server response in the serial log.
Recognised duplicate-file responses retry with a fresh number, up to
three uploads per save, using the same RAM snapshot. Other errors stop
the save. No SQL or policy changes are needed.

## 2026-10-05

### CI

The display build on GitHub Actions had failed since Wi-Fi was added.
Five display sources include the git-ignored `secrets.h`, so a clean
checkout could not compile them. The workflow now copies
`secrets_example.h` to `secrets.h` for the display job only, so CI
builds with empty credentials and nothing real reaches GitHub. Moved
`actions/checkout` to v5 to clear the Node 20 deprecation warnings.

## 2026-10-06

### Version 0.9.0

The display had stayed at 0.8.1 since the OTA test, so everything added
after it, accounts, cloud photos, the gallery, trace dragging and the
touch and photo numbering fixes, still reported 0.8.1. Boards 1 and 3 had
no version set and showed a git describe string instead. All three
projects now set `PROJECT_VER` to 0.9.0, checked in each built image, and
the three images go out together as one release, `v0.9.0`. Board 2 takes
it over Wi-Fi, boards 1 and 3 are flashed over USB.

</details>

<details>
<summary><b>Hardware</b>: the schematic decisions day by day, the parts that changed and why</summary>

## 2026-09-16

Created the KiCad project. Pushed the design docs and requirements.

## 2026-09-18

Six hierarchical sheets on the root page: power, both AFE channels,
acquisition, display, generator. 2000x1500 mils each, two rows of three.
Empty so far.

Added hardware/datasheets/: PDFs untracked, README of links instead.
Two of the links I had were dead.

Made the project symbol library and drew the ADS7883. Pin numbers checked
against SLAS594 p.5.

Took me a while to work out that the pin X/Y is where the pin meets the
body, not the end of the stub.

## 2026-09-19

Drew the dev board symbol. 44 pins, numbered by header position with the
board in front of me.

Didn't use KiCad's built-in WROOM-1 symbol,  that's the bare module and the
header order is completely different.

GPIO35-37 are broken out on the header but the octal PSRAM uses them.
Noted on the symbol.

Drew the LCD 40-pin symbol. Was working off the 5.0 inch datasheet at first
and caught it, wrong touch controller, wrong backlight, and three pins the
7.0 inch part actually uses are NC on the 5.0.

Renamed pins 35 and 36 from SCL/SDA to SPI_SCK/SPI_MOSI. They're SPI, and
the GT911 touch I2C on the same sheet is already using those names. 

Drew the GT911 touch symbol. Six pins, same datasheet page as the LCD
connector.

## 2026-09-20

Power sheet. USB input, 0R rail split, MCP1700 to +3V3_A.

No ferrite bead in the BOM so fitted 0R instead.

2.2 V reference. 10k/20k off +3V3_A, buffered with half the MCP6292.
Tied off the spare half.

ERC needed a second PWR_FLAG after R1. The resistor splits the net so
the flag on +5V doesn't reach the other side.

VREF_2V2 as a power symbol fails ERC. Made it a global label.

BNC input on ch1. Shell to GND, centre pin is the signal.

Wrote the safety note on the sheet. The shell is system ground, which
is USB ground, which is mains earth. Not isolated.

Divider on ch1. 750k/250k off the BNC, bottom of the stack goes to
VREF_2V2 instead of GND, which is what shifts the signal into the
ADC window.

Trimmers go across each resistor, not to ground. R4*C5 = R5*C6.

BAV99 clamp on the divider junction. Pin 3 is the middle tap, the two
diodes are in series, not a common-cathode pair.

R4 is doing two jobs. It's the attenuator and it's what limits fault
current into the diodes.

Buffer on ch1. MCP6292 as a follower off the divider junction.

The divider is 188k out. The ADS7883 wants under 200 ohm, so the
buffer isn't optional.

Filter and sheet exit on ch1. 150R with two 2.2nF C0G in parallel,
241kHz corner. C0G because X7R shifts with temperature and DC bias.

Tied off U3B as a grounded follower. No-connects would have left the
inputs floating, which on a CMOS part means the output sits on a rail.

One ERC error left, CH1_ANALOG has nowhere to go until the acquisition
sheet exists.

Copied ch1 to ch2. Designators auto-incremented, but the notes carry
part numbers so those had to be retyped.

### Pin map

First pass, verified against the ESP32-S3 GPIO reference and IO MUX tables.
Check against the Lonely Binary header diagram before wiring.

### Board 1, acquisition

| Signal | GPIO | Note |
|---|---|---|
| CH1_SCLK | 12 | SPI2 IO_MUX (FSPICLK) |
| CH1_SDO | 13 | SPI2 IO_MUX (FSPIQ) |
| CH1_CS | 10 | SPI2 IO_MUX (FSPICS0), 10k pull-up |
| CH2_SCLK | 15 | SPI3, GPIO matrix |
| CH2_SDO | 16 | SPI3, GPIO matrix |
| CH2_CS | 17 | SPI3, GPIO matrix, 10k pull-up |
| ENC1_A | 4 | |
| ENC1_B | 5 | |
| ENC1_SW | 6 | |
| ENC2_A | 7 | |
| ENC2_B | 8 | |
| ENC2_SW | 9 | |
| ENC3_A | 18 | |
| ENC3_B | 21 | |
| ENC3_SW | 38 | |
| BTN_RUN | 39 | JTAG MTCK |
| BTN_SINGLE | 40 | JTAG MTDO |
| BTN_GEN | 41 | JTAG MTDI |
| LED_RUN | 42 | JTAG MTMS |
| LED_TRIG | 47 | |
| LED_ARM | 1 | |
| STATUS_RGB | 48 | onboard WS2812, driven over RMT |
| LINK1_TX | 43 | U0TXD, use UART1 |
| LINK1_RX | 44 | U0RXD, use UART1 |

Spare: 2, 11, 14

### Board 2, display and hub

| Signal | GPIO | Note |
|---|---|---|
| LCD_R3 | 1 | |
| LCD_R4 | 2 | |
| LCD_R5 | 4 | |
| LCD_R6 | 5 | |
| LCD_R7 | 6 | |
| LCD_G2 | 7 | |
| LCD_G3 | 8 | |
| LCD_G4 | 9 | |
| LCD_G5 | 10 | |
| LCD_G6 | 11 | |
| LCD_G7 | 12 | |
| LCD_B3 | 13 | |
| LCD_B4 | 14 | |
| LCD_B5 | 15 | |
| LCD_B6 | 16 | |
| LCD_B7 | 17 | |
| LCD_DCLK | 18 | |
| LCD_HSYNC | 21 | |
| LCD_VSYNC | 38 | |
| LCD_DE | 39 | JTAG MTCK |
| TOUCH_SDA | 40 | JTAG MTDO, 4.7k pull-up |
| TOUCH_SCL | 41 | JTAG MTDI, 4.7k pull-up |
| TOUCH_INT | 42 | JTAG MTMS, must be driveable |
| LINK2_TX | 47 | to board 3 |
| LINK1_TX | 43 | U0TXD, use UART1 |
| LINK1_RX | 44 | U0RXD, use UART1 |
| TOUCH_RESET | 48 | shares onboard WS2812, asserts once at startup |

Spare: none

### Board 3, generator

| Signal | GPIO | Note |
|---|---|---|
| DAC_D0 | 4 | |
| DAC_D1 | 5 | |
| DAC_D2 | 6 | |
| DAC_D3 | 7 | |
| DAC_D4 | 8 | |
| DAC_D5 | 9 | |
| DAC_D6 | 10 | |
| DAC_D7 | 11 | |
| OUT_EN | 12 | 10k pull-down, output off at boot |
| LINK2_RX | 44 | U0RXD, use UART1 |

Spare: 1, 2, 13, 14, 15, 16, 17, 18, 21, 38, 39, 40, 41, 42, 43, 47, 48

### Reserved on all three boards

| Range | Why |
|---|---|
| 26-32 | SPI flash |
| 33-37 | octal PSRAM (N16R8) |
| 19-20 | native USB Serial/JTAG |
| 0, 3, 45, 46 | strapping |

Leaves 27 usable: 1, 2, 4-18, 21, 38-44, 47, 48.

LINK2 is TX only. Board 2 sends generator settings and gets nothing back.
That is what makes board 2 fit in 27 pins.

Every GPIO comes out of reset as an input with no pull. Both ADC chip
selects need a 10k pull-up so the converters are deselected before firmware
runs, and OUT_EN needs a 10k pull-down so the generator output is off at
boot.

GPIO39-42 are the external JTAG pins. Using them as GPIO means no external
JTAG adapter. The built-in USB JTAG does not use them, so debugging over
USB is unaffected.

GPIO43/44 are UART0's default pins. Route the inter-board links through
UART1 and put the console on USB Serial/JTAG
(CONFIG_ESP_CONSOLE_USB_SERIAL_JTAG), or the boot log goes out the link
cable. UART0 download mode is gone either way.

Board 3 DAC_D0-D7 sit on GPIO4-11, contiguous inside the GPIO_OUT register
(GPIO0-31). All eight bits write in one masked register write. Keep them in
that range if this gets rearranged.

GPIO48 is the onboard WS2812, an addressable LED, not a plain one. On board
1 it is the status LED. On board 2 it shares TOUCH_RESET, which asserts once
at startup, so the LED stays quiet.

## 2026-09-21

Acquisition sheet. Both ADS7883s on separate SPI hosts, encoders,
buttons, LEDs, LINK1 header.

Pull-ups on both CS lines. Every GPIO floats until firmware sets it
up, so without them the ADCs could think they're selected at boot.

Display sheet. RGB565 bus to the 7 inch panel, GT911 touch,
XL6009 for the backlight.

Panel is 24-bit, only the top 16 bits are driven. Tied the other
eight low. Panel SPI tied off too, no pins left on board 2.

Board 2's 3V3 regulator feeds the panel and touch, not +3V3_A.

Crossed LINK1 on the root sheet by pin order, TX opposite RX, so
the wires run straight.

Generator sheet. 8-bit R-2R ladder off GPIO4-11, Sallen-Key filter,
51R out to the BNC.

The ladder's own 10k output impedance is the filter's first resistor,
so one op-amp does filter and buffer.

Dropped OUT_EN from the pin map. Nothing to switch, and the ladder
already sits at 0V at boot through the terminator.

## 2026-09-30

Generator ladder moved to one value. Every 2R leg is a single 10k and
every R is two 10k in parallel (5k), 23 parts, no 20k. Same-value parts
hold the 2:1 ratio, and parallel pairs take less breadboard than series.
Ladder output is now 5k, so the Sallen-Key corner moves from 23 kHz
(Q 0.73) to 33 kHz (Q 0.69) with R38 kept at 10k. Filter note and
ladder note updated on the sheet.

## 2026-10-02

Front-end decoupling. The scope trace had visible fuzz on a flat input.
The ADS7883 uses VDD as its reference, so any noise on the analog rail
shows up as code noise. Everything on the rail was 1 uF or smaller.

Added:

- 10 uF on the MCP1700 output (+3.3VA), beside C2.
- 10 uF on the MCP1700 input (+5V), beside C1.
- 10 uF at each ADS7883 VDD, beside the existing 1 uF and 10 nF, in the
  same breadboard row as the pin.
- 1 uF across R3, the 20k of the VREF divider. It filters the 2.2 V
  reference at the divider (about 24 Hz with the 6.7k source), not on the
  buffer output, where a capacitive load could make the follower oscillate.

The noise on the trace dropped to a low level.

Schematic labels fixed: the op-amps and both ADS7883s were drawn on
+3V3, the dev board's digital rail, but on the bench they run from the
MCP1700 rail. Moved them to +3.3VA so the drawing matches the wiring.
Digital pull-ups stay on +3V3. Notes added next to the new parts.

Link series resistors. One 220R on each link wire: R40 (board 1 TX)
and R11 (board 1 RX) for LINK1, R41 (board 2 TX) for LINK2. They limit
the current into an unpowered board's ESD diode when one board is
unplugged while another drives the line, and damp ringing on the
jumpers. At 2 Mbaud the RC is about 5 ns against a 500 ns bit. Matches
the bench.

Front-end power. The 9 V breadboard power module overheated again and
the 3.3 V analog rail sagged to about 2.9 V. Since that rail is also the
ADC reference, every reading moved with it. The module is out. The +5V
rail now comes from a regulated 5 V adapter, and the MCP1700 stays cool
and holds 3.27 V. The front end draws only a few mA, so the heat was the
module's own wiring or load, not this circuit.

</details>

<details>
<summary><b>Software</b>: setting up Supabase and proving one user can never reach another's data</summary>

## 2026-10-03

Created `oscil-dev` in Supabase, in West US. Email sign-in is enabled,
confirmation is off. The device uses local account addresses that cannot
receive mail.

Applied `schema.sql` in the SQL editor. Supabase returned "Success. No rows
returned." The script creates `profiles`, `recovery` and `screenshots`, enables
row-level security, and creates a private screenshots bucket with a 64 KiB
file limit. Profile and screenshot policies restrict access to the signed-in
owner. Recovery has no client policies and its client grants are revoked.

The SQL is saved in the repo. The successful query confirms setup,
account and isolation checks were run separately below.

Supabase schema created

Deployed the `account` Edge Function from `index.ts`, with Verify JWT off.
The source uses Supabase's server-side service-role key to create the Auth
user, profile and recovery hash. The secret phrase is normalised and hashed
with PBKDF2-SHA256, a random salt and 100,000 iterations.

Tested signup from PowerShell with `paul_test`. The first request returned
`ok: True`. Repeating it returned HTTP 409 Conflict, rejecting the duplicate
username. Password reset, lockout and cross-account isolation were checked
with the two-user test below.

Account signup and duplicate rejection

Ran `tests/isolation_test.py` against `oscil-dev`. All 17 checks passed.
Both users could sign up and sign in. A uploaded a file and added its row,
B could not list or download it, write into A's folder, or insert a row as A.
The signed-out request returned no screenshots, and the recovery hash read
was refused. A could still read its own row.

Password reset refused the wrong phrase and accepted the right phrase with
different case and spacing. The old password stopped working, the new one
worked, and five wrong phrases locked further resets.

The PC's `python` command first resolved to MSYS2. Used Windows Python 3.13,
installed `requests` there, and set the Supabase URL and publishable key in
the PowerShell environment. The final run returned `ALL PASS`.

Supabase isolation tests passed

Raised the screenshots bucket limit from 64 KiB to 2 MB for the device's
800 x 480 BMP photos (1,152,054 bytes each). The change is saved in
`schema.sql`, the bucket stays private with the same owner policies.

</details>

---

## Known limits

A breadboard prototype on three dev boards, not a lab instrument.

- Sampling tops out at about 620 kSa/s per burst, 12 bits per channel.
- The link carries 31.8 frames/s, and the screen draws fewer, about 5 to
  20 frames/s depending on the view.
- The generator output is 0 to 3.3 V only, with no gain or offset stage.
- Wi-Fi is 2.4 GHz only, and credentials are compiled in from a
  git-ignored file. There is no on-device Wi-Fi setup yet.
- Photos are saved only to the cloud and only while signed in.

---

## What's next

- A custom PCB in KiCad to replace the breadboards and dev boards.
- A 3D-printed enclosure.
- A gain and offset stage on the generator output.

Concept drawings of the next step, not built yet:

| | | |
|---|---|---|
| <br>The handheld, 1.2 in thick | <br>The case drawing | <br>One PCB and the assembly |

---

## Design documents

| Document | Description |
|---|---|
| [`design_v0.pdf`](design_v0.pdf) | Full design, all sections in one document |
| [`Oscil_bill_of_materials_bom.xlsx`](Oscil_bill_of_materials_bom.xlsx) | Bill of materials |

PNG versions of each diagram are in [`screenshots_and_videos/`](screenshots_and_videos/).

---

## Revision history

| Rev | Date | Firmware | Change |
|---|---|---|---|
| 0.1 | 2026-09-16 | none | Initial design: use cases, requirements, architecture. Nothing built. |
| 0.2 | 2026-09-22 | unversioned | Hardware Rev A schematic complete. Firmware started. |
| 0.3 | 2026-09-30 | unversioned | ADC capture, trigger, board links, display, touch and generator running. |
| 0.4 | 2026-10-02 | unversioned | Touch and knob controls, generator screen, saved settings, two-point calibration, 16 MB OTA partition table. |
| 0.5 | 2026-10-03 | 0.8.1 | Wi-Fi, HTTPS OTA with self-test, Supabase accounts and cloud photo saves. |
| 0.6 | 2026-10-04 | 0.8.1 | Photo gallery and viewer on the device, trace dragging, photo numbering fix. |
| 0.7 | 2026-10-06 | 0.9.0 | One version across all three boards, released together as v0.9.0. New front page, MIT license. |

---

## License

[MIT](LICENSE). Use whatever helps, just keep the copyright notice.

Built by [Paul Simbulan](https://paulsimbulan.com)

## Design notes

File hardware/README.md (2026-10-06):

# Hardware

Rev A schematic for Oscil, drawn in KiCad 10. Three ESP32-S3 dev boards on
breadboards: one acquires, one drives the display, one generates signals.

**[Schematic PDF, Rev A](docs/Oscil-Schematic-RevA-05-Final.pdf)**
· [Pin map](docs/pin-map.md)
· [BOM](../Oscil_bill_of_materials_bom.xlsx)
· [Datasheets](../datasheets/)

Status: schematic complete, ERC clean. All three boards are built and
running on breadboards: every assigned GPIO was checked against the
schematic, the analog rail has extra decoupling, and the front end runs
from a regulated 5 V adapter (see the build logs).

## Sheets

### Root

Root sheet

Seven hierarchical sheets. Signals cross between boards through sheet pins,
so each sheet declares its own interface. Power rails are global.

### Power

Power sheet

The analog side gets its own MCP1700, split off the shared 5 V, so the ADCs
never share a regulator with Wi-Fi or the display. A buffered 2.2 V
reference sets the input offset for both channels.

### Analog front end

AFE channel 1

A compensated 750k/250k divider maps ±5 V into the ADC window, a BAV99
clamps anything past the rails, an MCP6292 buffers it, and a 150 Ω + 4.4 nF
filter sits in front of the converter. The 150 Ω is set by the ADS7883's
source impedance limit (SLAS594 p.11), not by the corner frequency. Channel
2 is identical.

AFE channel 2

### Acquisition

Acquisition sheet

Two ADS7883s on separate SPI hosts, so both channels sample at the same
instant rather than one after the other. Encoders, buttons and LEDs for the
front panel. Pull-ups hold both chip selects high until firmware takes over.

### Display

Display sheet

7" 800×480 RGB panel on a 16-bit parallel bus, GT911 touch over I²C, and an
XL6009 boost for the 25.6 V backlight. This board uses all 27 free GPIOs,
which is why the link to the generator is transmit only.

### Generator

Generator sheet

Firmware DDS into an 8-bit R-2R ladder, then a Sallen-Key filter at about
33 kHz. The ladder is all 10k: each 2R is one 10k and each R is two 10k in
parallel, so the 2:1 ratio holds by construction. Its own 5k output
impedance is the filter's first resistor, so one op-amp filters and buffers.

## On the bench

Rev A is built on breadboards around three ESP32-S3 dev boards. These are
from bring-up, each part checked on its own before the boards were joined.

| | |
|---|---|
| <br>The analog 3.3 V rail from the MCP1700 | <br>Hand-soldering the ADS7883s onto adapters |
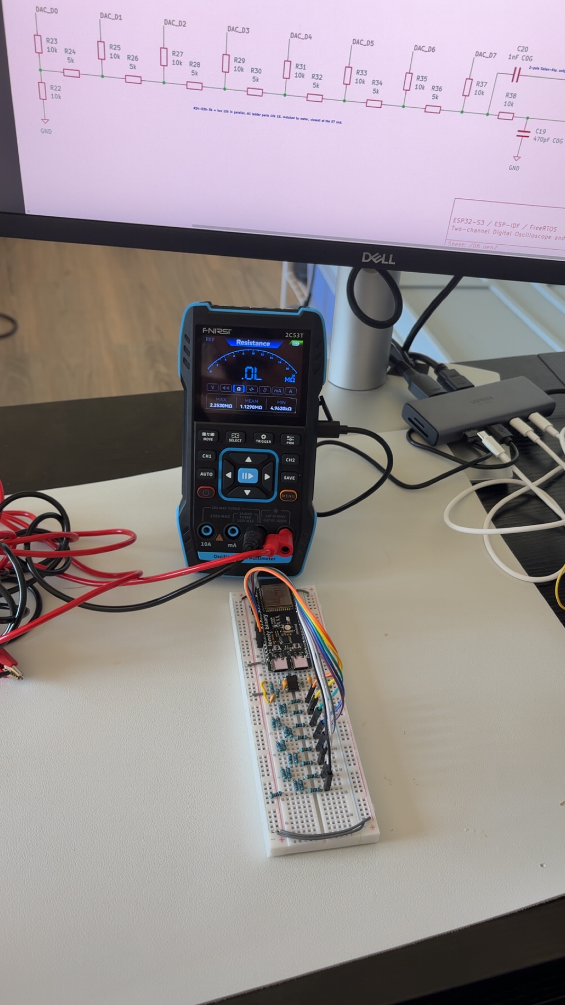
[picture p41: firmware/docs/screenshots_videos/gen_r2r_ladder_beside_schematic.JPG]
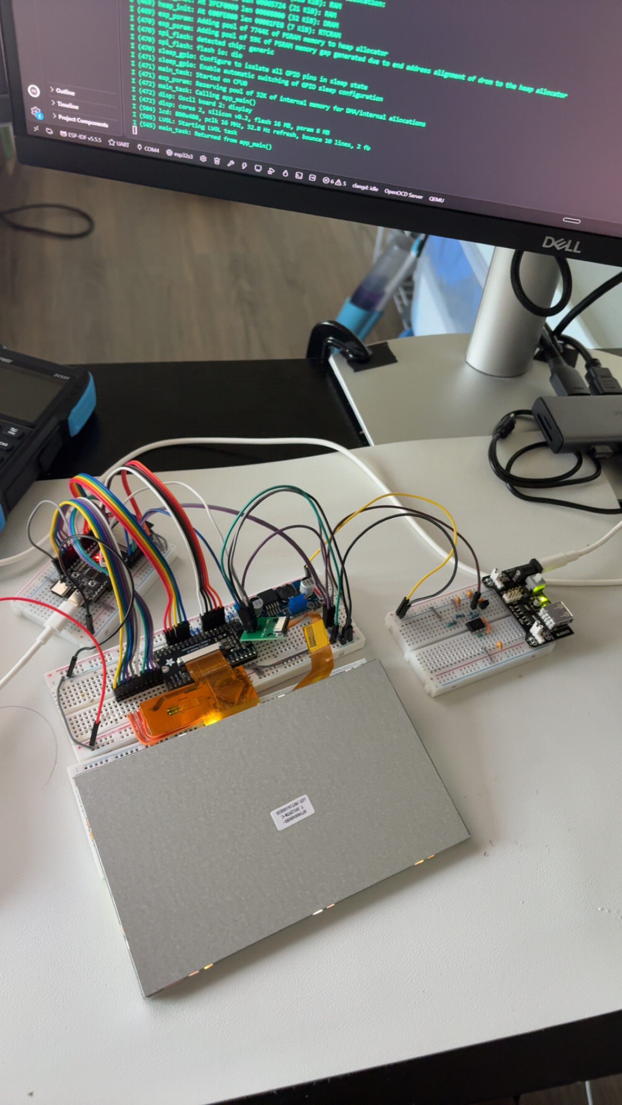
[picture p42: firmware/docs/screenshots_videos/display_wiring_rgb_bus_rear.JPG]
| <br>The R-2R ladder built beside its sheet | <br>The 16-bit RGB bus to the display |

## For Rev B

- C0G filter caps. Rev A uses a generic ceramic kit, values checked with a meter.
- A custom PCB with bare WROOM-1U modules instead of dev boards and breadboards.
- A 3D-printed enclosure.
- A gain and offset stage on the generator output. Rev A is 0 to 3.3 V only.

---
---

# Build log

<details>
<summary><b>Open the hardware build log</b>: the schematic decisions day by day, the parts that changed and why</summary>

## 2026-09-16

Created the KiCad project. Pushed the design docs and requirements.

## 2026-09-18

Six hierarchical sheets on the root page: power, both AFE channels,
acquisition, display, generator. 2000x1500 mils each, two rows of three.
Empty so far.

Added hardware/datasheets/: PDFs untracked, README of links instead.
Two of the links I had were dead.

Made the project symbol library and drew the ADS7883. Pin numbers checked
against SLAS594 p.5.

Took me a while to work out that the pin X/Y is where the pin meets the
body, not the end of the stub.

## 2026-09-19

Drew the dev board symbol. 44 pins, numbered by header position with the
board in front of me.

Didn't use KiCad's built-in WROOM-1 symbol,  that's the bare module and the
header order is completely different.

GPIO35-37 are broken out on the header but the octal PSRAM uses them.
Noted on the symbol.

Drew the LCD 40-pin symbol. Was working off the 5.0 inch datasheet at first
and caught it, wrong touch controller, wrong backlight, and three pins the
7.0 inch part actually uses are NC on the 5.0.

Renamed pins 35 and 36 from SCL/SDA to SPI_SCK/SPI_MOSI. They're SPI, and
the GT911 touch I2C on the same sheet is already using those names. 

Drew the GT911 touch symbol. Six pins, same datasheet page as the LCD
connector.

## 2026-09-20

Power sheet. USB input, 0R rail split, MCP1700 to +3V3_A.

No ferrite bead in the BOM so fitted 0R instead.

2.2 V reference. 10k/20k off +3V3_A, buffered with half the MCP6292.
Tied off the spare half.

ERC needed a second PWR_FLAG after R1. The resistor splits the net so
the flag on +5V doesn't reach the other side.

VREF_2V2 as a power symbol fails ERC. Made it a global label.

BNC input on ch1. Shell to GND, centre pin is the signal.

Wrote the safety note on the sheet. The shell is system ground, which
is USB ground, which is mains earth. Not isolated.

Divider on ch1. 750k/250k off the BNC, bottom of the stack goes to
VREF_2V2 instead of GND, which is what shifts the signal into the
ADC window.

Trimmers go across each resistor, not to ground. R4*C5 = R5*C6.

BAV99 clamp on the divider junction. Pin 3 is the middle tap, the two
diodes are in series, not a common-cathode pair.

R4 is doing two jobs. It's the attenuator and it's what limits fault
current into the diodes.

Buffer on ch1. MCP6292 as a follower off the divider junction.

The divider is 188k out. The ADS7883 wants under 200 ohm, so the
buffer isn't optional.

Filter and sheet exit on ch1. 150R with two 2.2nF C0G in parallel,
241kHz corner. C0G because X7R shifts with temperature and DC bias.

Tied off U3B as a grounded follower. No-connects would have left the
inputs floating, which on a CMOS part means the output sits on a rail.

One ERC error left, CH1_ANALOG has nowhere to go until the acquisition
sheet exists.

Copied ch1 to ch2. Designators auto-incremented, but the notes carry
part numbers so those had to be retyped.

### Pin map

First pass, verified against the ESP32-S3 GPIO reference and IO MUX tables.
Check against the Lonely Binary header diagram before wiring.

### Board 1, acquisition

| Signal | GPIO | Note |
|---|---|---|
| CH1_SCLK | 12 | SPI2 IO_MUX (FSPICLK) |
| CH1_SDO | 13 | SPI2 IO_MUX (FSPIQ) |
| CH1_CS | 10 | SPI2 IO_MUX (FSPICS0), 10k pull-up |
| CH2_SCLK | 15 | SPI3, GPIO matrix |
| CH2_SDO | 16 | SPI3, GPIO matrix |
| CH2_CS | 17 | SPI3, GPIO matrix, 10k pull-up |
| ENC1_A | 4 | |
| ENC1_B | 5 | |
| ENC1_SW | 6 | |
| ENC2_A | 7 | |
| ENC2_B | 8 | |
| ENC2_SW | 9 | |
| ENC3_A | 18 | |
| ENC3_B | 21 | |
| ENC3_SW | 38 | |
| BTN_RUN | 39 | JTAG MTCK |
| BTN_SINGLE | 40 | JTAG MTDO |
| BTN_GEN | 41 | JTAG MTDI |
| LED_RUN | 42 | JTAG MTMS |
| LED_TRIG | 47 | |
| LED_ARM | 1 | |
| STATUS_RGB | 48 | onboard WS2812, driven over RMT |
| LINK1_TX | 43 | U0TXD, use UART1 |
| LINK1_RX | 44 | U0RXD, use UART1 |

Spare: 2, 11, 14

### Board 2, display and hub

| Signal | GPIO | Note |
|---|---|---|
| LCD_R3 | 1 | |
| LCD_R4 | 2 | |
| LCD_R5 | 4 | |
| LCD_R6 | 5 | |
| LCD_R7 | 6 | |
| LCD_G2 | 7 | |
| LCD_G3 | 8 | |
| LCD_G4 | 9 | |
| LCD_G5 | 10 | |
| LCD_G6 | 11 | |
| LCD_G7 | 12 | |
| LCD_B3 | 13 | |
| LCD_B4 | 14 | |
| LCD_B5 | 15 | |
| LCD_B6 | 16 | |
| LCD_B7 | 17 | |
| LCD_DCLK | 18 | |
| LCD_HSYNC | 21 | |
| LCD_VSYNC | 38 | |
| LCD_DE | 39 | JTAG MTCK |
| TOUCH_SDA | 40 | JTAG MTDO, 4.7k pull-up |
| TOUCH_SCL | 41 | JTAG MTDI, 4.7k pull-up |
| TOUCH_INT | 42 | JTAG MTMS, must be driveable |
| LINK2_TX | 47 | to board 3 |
| LINK1_TX | 43 | U0TXD, use UART1 |
| LINK1_RX | 44 | U0RXD, use UART1 |
| TOUCH_RESET | 48 | shares onboard WS2812, asserts once at startup |

Spare: none

### Board 3, generator

| Signal | GPIO | Note |
|---|---|---|
| DAC_D0 | 4 | |
| DAC_D1 | 5 | |
| DAC_D2 | 6 | |
| DAC_D3 | 7 | |
| DAC_D4 | 8 | |
| DAC_D5 | 9 | |
| DAC_D6 | 10 | |
| DAC_D7 | 11 | |
| OUT_EN | 12 | 10k pull-down, output off at boot |
| LINK2_RX | 44 | U0RXD, use UART1 |

Spare: 1, 2, 13, 14, 15, 16, 17, 18, 21, 38, 39, 40, 41, 42, 43, 47, 48

### Reserved on all three boards

| Range | Why |
|---|---|
| 26-32 | SPI flash |
| 33-37 | octal PSRAM (N16R8) |
| 19-20 | native USB Serial/JTAG |
| 0, 3, 45, 46 | strapping |

Leaves 27 usable: 1, 2, 4-18, 21, 38-44, 47, 48.

LINK2 is TX only. Board 2 sends generator settings and gets nothing back.
That is what makes board 2 fit in 27 pins.

Every GPIO comes out of reset as an input with no pull. Both ADC chip
selects need a 10k pull-up so the converters are deselected before firmware
runs, and OUT_EN needs a 10k pull-down so the generator output is off at
boot.

GPIO39-42 are the external JTAG pins. Using them as GPIO means no external
JTAG adapter. The built-in USB JTAG does not use them, so debugging over
USB is unaffected.

GPIO43/44 are UART0's default pins. Route the inter-board links through
UART1 and put the console on USB Serial/JTAG
(CONFIG_ESP_CONSOLE_USB_SERIAL_JTAG), or the boot log goes out the link
cable. UART0 download mode is gone either way.

Board 3 DAC_D0-D7 sit on GPIO4-11, contiguous inside the GPIO_OUT register
(GPIO0-31). All eight bits write in one masked register write. Keep them in
that range if this gets rearranged.

GPIO48 is the onboard WS2812, an addressable LED, not a plain one. On board
1 it is the status LED. On board 2 it shares TOUCH_RESET, which asserts once
at startup, so the LED stays quiet.

## 2026-09-21

Acquisition sheet. Both ADS7883s on separate SPI hosts, encoders,
buttons, LEDs, LINK1 header.

Pull-ups on both CS lines. Every GPIO floats until firmware sets it
up, so without them the ADCs could think they're selected at boot.

Display sheet. RGB565 bus to the 7 inch panel, GT911 touch,
XL6009 for the backlight.

Panel is 24-bit, only the top 16 bits are driven. Tied the other
eight low. Panel SPI tied off too, no pins left on board 2.

Board 2's 3V3 regulator feeds the panel and touch, not +3V3_A.

Crossed LINK1 on the root sheet by pin order, TX opposite RX, so
the wires run straight.

Generator sheet. 8-bit R-2R ladder off GPIO4-11, Sallen-Key filter,
51R out to the BNC.

The ladder's own 10k output impedance is the filter's first resistor,
so one op-amp does filter and buffer.

Dropped OUT_EN from the pin map. Nothing to switch, and the ladder
already sits at 0V at boot through the terminator.

## 2026-09-30

Generator ladder moved to one value. Every 2R leg is a single 10k and
every R is two 10k in parallel (5k), 23 parts, no 20k. Same-value parts
hold the 2:1 ratio, and parallel pairs take less breadboard than series.
Ladder output is now 5k, so the Sallen-Key corner moves from 23 kHz
(Q 0.73) to 33 kHz (Q 0.69) with R38 kept at 10k. Filter note and
ladder note updated on the sheet.

## 2026-10-02

Front-end decoupling. The scope trace had visible fuzz on a flat input.
The ADS7883 uses VDD as its reference, so any noise on the analog rail
shows up as code noise. Everything on the rail was 1 uF or smaller.

Added:

- 10 uF on the MCP1700 output (+3.3VA), beside C2.
- 10 uF on the MCP1700 input (+5V), beside C1.
- 10 uF at each ADS7883 VDD, beside the existing 1 uF and 10 nF, in the
  same breadboard row as the pin.
- 1 uF across R3, the 20k of the VREF divider. It filters the 2.2 V
  reference at the divider (about 24 Hz with the 6.7k source), not on the
  buffer output, where a capacitive load could make the follower oscillate.

The noise on the trace dropped to a low level.

Schematic labels fixed: the op-amps and both ADS7883s were drawn on
+3V3, the dev board's digital rail, but on the bench they run from the
MCP1700 rail. Moved them to +3.3VA so the drawing matches the wiring.
Digital pull-ups stay on +3V3. Notes added next to the new parts.

Link series resistors. One 220R on each link wire: R40 (board 1 TX)
and R11 (board 1 RX) for LINK1, R41 (board 2 TX) for LINK2. They limit
the current into an unpowered board's ESD diode when one board is
unplugged while another drives the line, and damp ringing on the
jumpers. At 2 Mbaud the RC is about 5 ns against a 500 ns bit. Matches
the bench.

Front-end power. The 9 V breadboard power module overheated again and
the 3.3 V analog rail sagged to about 2.9 V. Since that rail is also the
ADC reference, every reading moved with it. The module is out. The +5V
rail now comes from a regulated 5 V adapter, and the MCP1700 stays cool
and holds 3.27 V. The front end draws only a few mA, so the heat was the
module's own wiring or load, not this circuit.

</details>

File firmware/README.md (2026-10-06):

# Firmware

Three ESP-IDF projects, one per board, plus shared C code and host tests.

| Board | Folder | Job |
|---|---|---|
| 1 | [`acq/`](acq/) | Samples both ADCs, triggers, reads the front panel, sends frames over LINK1 |
| 2 | [`display/`](display/) | Draws the scope, runs the UI, drives the generator over LINK2, Wi-Fi, OTA, accounts |
| 3 | [`gen/`](gen/) | DDS into the 8-bit R-2R DAC, follows LINK2 |



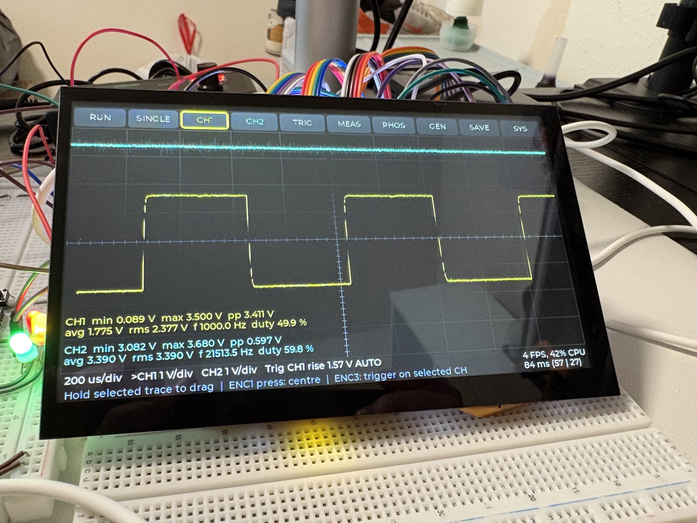
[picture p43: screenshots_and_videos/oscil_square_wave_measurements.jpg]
Square wave with live measurements on the display


## Firmware skills

Bare metal means my own register-level driver. Everything else is built on
ESP-IDF, FreeRTOS or LVGL.

| Area | What it does | Layer | Code |
|---|---|---|---|
| **C** | All firmware, no C++ | | everything |
| **GPIO** | Pin setup, IOMUX and fast set/clear through the GPIO registers | Bare metal | [`shared/oscil_gpio.h`](shared/oscil_gpio.h) |
| **Bit-banged protocol** | WS2812 status LED timed from the CPU cycle counter | Bare metal | [`shared/oscil_status.c`](shared/oscil_status.c) |
| **SPI** | SPI2 set up from its registers, two ADS7883 ADCs read in one dual-line frame at 26.67 MHz | Bare metal | [`acq/main/spi2_adc.c`](acq/main/spi2_adc.c) |
| **DMA** | GDMA linked-list descriptors built by hand for burst capture, up to about 620 kSa/s | Bare metal | [`acq/main/sampler.c`](acq/main/sampler.c) |
| **UART** | UART1/2 driver from the registers, interrupt handler and ring buffer each way, 2 Mbaud | Bare metal | [`shared/oscil_uart.c`](shared/oscil_uart.c) |
| **Interrupts** | Timer Group 0 interrupt at 100 kHz for DDS, ISR and its data kept in IRAM | Bare metal | [`gen/main/gen.c`](gen/main/gen.c) |
| **Board link protocol** | COBS framing, CRC-16, sequence numbers, lost-frame counting, resync after garbage | Portable C | [`shared/oscil_link.c`](shared/oscil_link.c) |
| **Parallel RGB display** | 800 x 480 panel on a 16-bit parallel RGB bus, 16 MHz pixel clock, two framebuffers in PSRAM, bounce buffers | ESP-IDF `esp_lcd` | [`display/main/lcd.c`](display/main/lcd.c) |
| **I2C** | GT911 touch controller as an LVGL input device, error recovery on a bad read | ESP-IDF I2C master | [`display/main/touch.c`](display/main/touch.c) |
| **GUI** | LVGL 9.3 scope, generator, account and photo screens, rendering on core 1 | LVGL | [`display/main/ui.c`](display/main/ui.c) |
| **FreeRTOS** | Tasks pinned to each core, queues, event groups, task notifications, software timers, critical sections | FreeRTOS | [`acq/main/acq_task.c`](acq/main/acq_task.c), [`display/main/net.c`](display/main/net.c) |
| **Inputs** | Three rotary encoders with a table-driven quadrature decoder, buttons debounced by a 1 kHz scan | Portable C + FreeRTOS | [`acq/main/panel.c`](acq/main/panel.c) |
| **Signal processing** | Edge trigger with hysteresis and sub-sample position, min/max decimation, true RMS, frequency, duty | Portable C | [`shared/`](shared/) |
| **DDS** | Phase-accumulator waveform synthesis into an 8-bit R-2R DAC | Portable C + bare metal | [`shared/oscil_dds.c`](shared/oscil_dds.c) |
| **Memory** | 8 MB PSRAM for framebuffers, photos and task stacks, code run from PSRAM (XIP), IRAM for ISRs, static FreeRTOS objects, heap capability allocation | ESP-IDF | [`display/main/ui_photos.c`](display/main/ui_photos.c), [`display/sdkconfig.defaults`](display/sdkconfig.defaults) |
| **Flash and NVS** | Custom 16 MB partition table with two 4 MB app slots, settings and calibration saved to NVS with a version and CRC | ESP-IDF | [`display/partitions.csv`](display/partitions.csv), [`display/main/settings.c`](display/main/settings.c), [`acq/main/cal.c`](acq/main/cal.c) |
| **OTA update** | HTTPS download into the other slot, self-test on first boot, rollback if it fails | ESP-IDF | [`display/main/ota.c`](display/main/ota.c) |
| **Wi-Fi and networking** | Event-driven station with exponential backoff, SNTP time, HTTPS with certificate checking (mbedTLS) | ESP-IDF | [`display/main/net.c`](display/main/net.c), [`display/main/cloud_http.c`](display/main/cloud_http.c) |
| **Cloud client** | Sign-in, token refresh, uploads and downloads to Supabase on worker tasks | ESP-IDF HTTP client | [`display/main/account.c`](display/main/account.c), [`display/main/upload.c`](display/main/upload.c) |
| **Testing** | Unity host tests for the portable C, run by CTest and GitHub Actions on every push | Unity, CMake | [`tests/`](tests/) |
| **Bring-up and debug** | Logic analyzer pin walks and SPI decodes, oscilloscope and multimeter checks, all in the build log | | [`docs/build_log.md`](docs/build_log.md) |

## Layout

```text
firmware/
  acq/       board 1
  display/   board 2
  gen/       board 3
  shared/    pin maps, protocol, link, trigger, DDS, measurements
  tests/     Unity host tests (CMake, CTest)
  tools/     PC scripts to capture and plot board data
  docs/      build log, photos, analyzer and scope captures
```

## Build

In a board folder, from the ESP-IDF terminal:

    idf.py set-target esp32s3
    idf.py build

Host tests, from the repo root:

    cmake -S firmware/tests -B build-host
    cmake --build build-host
    ctest --test-dir build-host --output-on-failure

Board 2 needs `display/main/secrets.h`. Copy `secrets_example.h` and fill
in Wi-Fi, the OTA URL and the Supabase project.

## Progress

| # | What | Status |
|---|---|---|
| 00 | Three projects, shared component, pin headers, sdkconfig defaults | Done |
| 01 | Host tests for the AFE math, CI on every push | Done |
| 02 | All three boards flash and report 16 MB flash, 8 MB PSRAM, 1 kHz tick | Done |
| 03 | Register-level GPIO, bit-banged WS2812 heartbeat on all three | Done |
| 04 | Pin walk: every GPIO checked against the schematic on the analyzer | Done |
| 05 | SPI speed test: GP-SPI2 from registers, frame rate measured | Done |
| 06 | Analog rail: MCP1700 makes +3V3_A (3.314 V) | Done |
| 07 | 2.2 V reference: divider + U2A buffer, VREF_2V2 = 2.214 V | Done |
| 08 | CH1 and CH2 front ends: offset (1.66 V) and open input (VREF) checked | Done |
| 09 | Front panel: 3 LEDs, 3 buttons debounced by a 1 kHz scan, events on a queue | Done |
| 10 | Encoders: 3 EC11s, table-driven quadrature decoder, one event per click | Done |
| 11 | First ADC reads: both ADS7883s clean at 10 MHz, CH1 calibrated to 0.001 V with IN grounded | Done |
| 12 | Noise floor at 26.67 MHz: 3.9 codes rms (12.6 mV at the BNC), SPI mode chosen from measurement | Done |
| 13 | Both channels from one dual-line SPI frame, bit de-interleave host-tested | Done |
| 14 | DMA burst capture: 3200 samples per burst, rate set by a hardware counter, checked against an on-board 1 kHz reference, up to about 620 kSa/s | Done |
| 15 | Edge trigger with hysteresis and sub-sample position, host-tested | Done |
| 16 | Min/max decimation to 800 display columns, single-sample spikes kept, host-tested | Done |
| 17 | Acquisition task on core 1: capture, trigger, min/max frame, RUN/STOP/SINGLE, 70 frames/s | Done |
| 18 | Board link protocol: COBS framing, CRC-16, resync and loss count, host-tested | Done |
| 19 | UART driver from the registers: 15,600 frames at 2 Mbaud in loopback, zero errors | Done |
| 20 | Board 1 to board 2 over LINK1: 31.8 frames/s of waveform data, panel events, settings round trip | Done |
| 21 | Display backlight from an XL6009 boost: 40 mA at 23 V, set and measured by hand | Done |
| 22 | RGB panel lit from a PSRAM framebuffer at 16 MHz: colour bars, bit bands, border | Done |
| 23 | 8-bit R-2R ladder, all eight bits in one GPIO_OUT store: every bit weight within 1% | Done |
| 24 | DDS in a 100 kHz register-level timer interrupt: sine, square, saw, triangle, host-tested | Done |
| 25 | LVGL 9.3 on the panel: double framebuffer, bounce buffers, rendering on core 1 | Done |
| 26 | GT911 touch over I2C at 0x5D, feeding LVGL as an input device | Done |
| 27 | Live scope view: board 1 frames drawn on board 2, link 31.8 frames/s error-free under display load | Done |
| 28 | Measurements on board 1 from the full record: min, max, pp, avg, true RMS, frequency, duty, host-tested | Done |
| 29 | Controls: knobs, buttons and touch through one action path, board 2 owns the settings, RUN/STOP/SINGLE | Done |
| 30 | Generator screen: shapes, keypad frequency, amplitude, offset, duty, live preview from the same DDS code | Done |
| 31 | LINK2: board 2 broadcasts the generator state on change and every 500 ms, board 3 applies it, no acknowledgement needed | Done |
| 32 | Settings saved to NVS with debounce and CRC, two-point calibration per channel, stored on board 1 and sent to board 2 | Done |
| 33 | 16 MB partition table on all boards: two 4 MB OTA slots, 7.9 MB storage, app rollback on | Done |
| 34 | Wi-Fi station on board 2: event-driven, exponential backoff reconnect, SNTP, credentials kept out of git | Done |
| 35 | SYS panel and HTTPS OTA: one-time NVS request, reboot without LCD for download, new-image self-test | Done |
| 36 | Supabase HTTPS client: sign-in, session saved in NVS, refresh after reboot, wrong-password rejection | Done |
| 37 | Touchscreen account screen: sign-in, create account, phrase reset and sign-out, software AES for TLS | Done |
| 38 | Cloud-only scope photos: signed-in SAVE, RAM snapshot, private BMP upload and busy guard | Done |
| 39 | Account photo list and single-photo viewer, hold and drag the selected scope trace | Done |
| 40 | Touch read errors recovered instead of rebooting, account worker stack in PSRAM | Built |
| 41 | Photo numbers continue after the account's highest saved photo, so a replacement board never collides | Built |
| 42 | CI builds the display with placeholder secrets | Done |
| 43 | Version 0.9.0 on all three boards, released together | Done |

## How the boards work together

- **Board 1** samples with DMA on core 1, triggers, decimates to 800 min/max
  columns, measures, and sends frames over LINK1. Knobs and buttons are
  scanned at 1 kHz on core 0.
- **Board 2** owns the settings. LVGL draws on core 1, the links and RGB
  interrupt stay on core 0. It sends settings to board 1 over LINK1 and the
  generator state to board 3 over LINK2, on every change and every 500 ms.
- **Board 3** listens on LINK2 (core 0) and runs the DDS interrupt on core 1,
  so link traffic never touches the output.

## Updates over Wi-Fi

- Releases: [latest](https://github.com/pajsimbulan/oscil/releases/latest). Board 2 updates itself, boards 1 and 3 flash over USB.
- SYS, Update saves a request to NVS and reboots.
- The next boot leaves the screen off, downloads the latest GitHub Release
  over HTTPS into the other app slot, and reboots into it.
- The new image keeps itself only if the LCD, touch and a board 1 frame
  check out within 5 s, otherwise it rolls back.
- Downloading with the screen off fixed crashes during flash writes, the
  build log has the details.

[Download log](docs/screenshots_videos/ota_update_mode_download.png) ·
[0.8.1 confirmed](docs/screenshots_videos/ota_0_8_1_confirmed_link_clean.png) ·
[video](docs/screenshots_videos/ota_update_0_8_0_to_0_8_1.MP4)

## Accounts

- Sign in, create an account, reset a password with a secret phrase, sign
  out, all on the touchscreen. Username only, no email.
- Refresh token in NVS, access token in RAM, so a reboot signs back in
  without the password.
- Requests run on a worker task with its stack in PSRAM, so the UI never
  waits on the network.
- TLS uses software AES, the hardware AES driver kept failing to get a
  DMA-capable buffer.
- Backend: [`software/`](../software/).

[Sign-in](docs/screenshots_videos/account_sign_in_screen.JPG) ·
[create account](docs/screenshots_videos/account_create_screen.PNG) ·
[session restored](docs/screenshots_videos/account_session_restored.png) ·
[wrong password](docs/screenshots_videos/account_wrong_password_rejected.png) ·
[reset video](docs/screenshots_videos/account_reset_new_password_sign_in.MP4)

## Cloud photos

- SAVE snapshots the scope into RAM and streams it row by row to the user's
  private Supabase folder as an 800 x 480 BMP. Nothing goes to flash.
- One upload at a time, signed-out saves are refused.
- Numbering continues from the account's highest photo, so a new board
  never overwrites an old one.
- My photos lists 20 per page. Tap one to load it into PSRAM, Close frees it.

[Saved](docs/screenshots_videos/cloud_photo_saved_to_account.JPG) ·
[sign-in required](docs/screenshots_videos/cloud_photo_sign_in_required.JPG) ·
[upload busy](docs/screenshots_videos/cloud_photo_upload_busy.JPG) ·
[viewer](docs/screenshots_videos/cloud_photo_viewer.JPG) ·
[video](docs/screenshots_videos/cloud_photo_save_busy_supabase.MOV)

## Touch and knobs

- Hold a trace 300 ms and drag. Up and down moves its offset, left and
  right pans it.
- ENC1 press recentres, ENC2 sets V/div, ENC2 press switches channel, ENC3
  sets the trigger level, TRIG cycles edge and mode.
- Tap a selected CH button to turn that channel on or off.

---

## Build log

<details>
<summary><b>Open the firmware build log</b>: every day from the first blink to cloud saves, with the bugs, the logic analyzer captures and how each one got fixed</summary>

## 2026-09-21

Started firmware. Three ESP-IDF projects, one per board, plus a shared
folder so pin numbers and the link protocol only exist once.

## 2026-09-22

sdkconfig.defaults in each: 16MB flash, octal PSRAM, 1000 Hz tick,
console on USB Serial/JTAG. The 2MB and 100 Hz defaults both bit me
in earlier lab work, so each build gets checked against sdkconfig.

Pin numbers from pin-map.md are in a header per board. Firmware
never uses a raw GPIO number.

AFE scaling in shared. The divider bottom sits on 2.2 V instead of
ground, so 0 V at the BNC reads 1.65 V at the ADC. Vbnc = 4 x (Vadc - 1.65).

First build couldn't find oscil_pins_acq.h. An include path would've
found the header but not compiled the .c, so shared is a real component
now. Also caught display and gen still named project(acq).

Host tests with Unity run the real oscil_afe.c on my PC. 4/4 pass.
They check the math, not the hardware. CI runs them on every push
that touches firmware, and the badge on the README shows the result.

Status LED heartbeat on all three boards. GPIO goes through registers
in oscil_gpio.h, no driver. The WS2812 is bit-banged off the CPU cycle
counter: 24 bits GRB, 0.4 or 0.85 us high in a 1.25 us bit, interrupts
masked for the ~30 us frame. Blink task pinned to core 0.
Acq green, display red, gen blue.

First build died on -Werror=misleading-indentation. A `while (...);`
wait loop with the next line one space off. Empty loops get `{ }` now.
First flash wasn't one either: only the monitor ran, and board 1 was
still booting an old lab.

Before: three projects, one command each

After: all three boot, heartbeat on GPIO48

Three boards blinking, click for video

Pin walk on board 1. The first pin in the list pulses once, the second
twice, and so on, then every pin is read back with the pull-up on.
26 pins, four batches of eight on the logic analyzer, every count
matched the schematic header. GPIO43 and 44 are the TX and RX pads
on the silkscreen, not numbered.

First read pass came back with random 0s. I was reading right after
turning on the 45k pull-up, and the pin had just been driven low, so it
hadn't charged yet. Pull-ups on for everything, 10 ms settle, then read:
all 1s every pass.

Each batch: analyzer GND to header 22, D0 to D7 on eight header pins,
1 MHz capture. Counting the pulses on a channel tells you which GPIO
is on that pin.

Board 1 wired to the analyzer, batch 1

Batch 1:

| Ch | Header | GPIO | Signal | Pulses | Seen |
|---|---|---|---|---|---|
| D0 | 4 | 4 | ENC1_A | 1 | ✓ |
| D1 | 5 | 5 | ENC1_B | 2 | ✓ |
| D2 | 6 | 6 | ENC1_SW | 3 | ✓ |
| D3 | 7 | 7 | ENC2_A | 4 | ✓ |
| D4 | 12 | 8 | ENC2_B | 5 | ✓ |
| D5 | 15 | 9 | ENC2_SW | 6 | ✓ |
| D6 | 8 | 15 | CH2_SCLK | 7 | ✓ |
| D7 | 9 | 16 | CH2_SDO | 8 | ✓ |

Batch 1: 1 to 8 pulses

Batch 2:

| Ch | Header | GPIO | Signal | Pulses | Seen |
|---|---|---|---|---|---|
| D0 | 10 | 17 | CH2_CS | 9 | ✓ |
| D1 | 16 | 10 | CH1_CS | 10 | ✓ |
| D2 | 11 | 18 | ENC3_A | 11 | ✓ |
| D3 | 18 | 12 | CH1_SCLK | 12 | ✓ |
| D4 | 19 | 13 | CH1_SDO | 13 | ✓ |
| D5 | 27 | 21 | ENC3_B | 14 | ✓ |
| D6 | 35 | 38 | ENC3_SW | 15 | ✓ |
| D7 | 36 | 39 | BTN_RUN | 16 | ✓ |

Batch 2: 9 to 16 pulses

Batch 3:

| Ch | Header | GPIO | Signal | Pulses | Seen |
|---|---|---|---|---|---|
| D0 | 37 | 40 | BTN_SINGLE | 17 | ✓ |
| D1 | 38 | 41 | BTN_GEN | 18 | ✓ |
| D2 | 39 | 42 | LED_RUN | 19 | ✓ |
| D3 | 28 | 47 | LED_TRIG | 20 | ✓ |
| D4 | 41 | 1 | LED_ARM | 21 | ✓ |
| D5 | 43 (TX) | 43 | LINK1_TX | 22 | ✓ |
| D6 | 42 (RX) | 44 | LINK1_RX | 23 | ✓ |
| D7 | 40 | 2 | spare | 24 | ✓ |

Batch 3: 17 to 24 pulses, TX and RX included

Batch 4:

| Ch | Header | GPIO | Signal | Pulses | Seen |
|---|---|---|---|---|---|
| D0 | 17 | 11 | spare | 25 | ✓ |
| D1 | 20 | 14 | spare | 26 | ✓ |

Batch 4: the two spares, 25 and 26

Pin walk on board 2. Same 26-pin idea, same header order as board 1, so
the analyzer wiring for each batch didn't change between boards. Every
count matched. GPIO48 stays off the list: it's the status LED now and
the touch reset later, so it gets checked when the touch panel goes on.

Batch 1:

| Ch | Header | GPIO | Signal | Pulses | Seen |
|---|---|---|---|---|---|
| D0 | 4 | 4 | LCD_R5 | 1 | ✓ |
| D1 | 5 | 5 | LCD_R6 | 2 | ✓ |
| D2 | 6 | 6 | LCD_R7 | 3 | ✓ |
| D3 | 7 | 7 | LCD_G2 | 4 | ✓ |
| D4 | 12 | 8 | LCD_G3 | 5 | ✓ |
| D5 | 15 | 9 | LCD_G4 | 6 | ✓ |
| D6 | 8 | 15 | LCD_B5 | 7 | ✓ |
| D7 | 9 | 16 | LCD_B6 | 8 | ✓ |

Board 2 batch 1: 1 to 8 pulses, red and green data lines

Batch 2:

| Ch | Header | GPIO | Signal | Pulses | Seen |
|---|---|---|---|---|---|
| D0 | 10 | 17 | LCD_B7 | 9 | ✓ |
| D1 | 16 | 10 | LCD_G5 | 10 | ✓ |
| D2 | 11 | 18 | LCD_DCLK | 11 | ✓ |
| D3 | 18 | 12 | LCD_G7 | 12 | ✓ |
| D4 | 19 | 13 | LCD_B3 | 13 | ✓ |
| D5 | 27 | 21 | LCD_HSYNC | 14 | ✓ |
| D6 | 35 | 38 | LCD_VSYNC | 15 | ✓ |
| D7 | 36 | 39 | LCD_DE | 16 | ✓ |

Board 2 batch 2: 9 to 16 pulses, the rest of the RGB bus and its sync lines

Batch 3:

| Ch | Header | GPIO | Signal | Pulses | Seen |
|---|---|---|---|---|---|
| D0 | 37 | 40 | TOUCH_SDA | 17 | ✓ |
| D1 | 38 | 41 | TOUCH_SCL | 18 | ✓ |
| D2 | 39 | 42 | TOUCH_INT | 19 | ✓ |
| D3 | 28 | 47 | LINK2_TX | 20 | ✓ |
| D4 | 41 | 1 | LCD_R3 | 21 | ✓ |
| D5 | 43 (TX) | 43 | LINK1_TX | 22 | ✓ |
| D6 | 42 (RX) | 44 | LINK1_RX | 23 | ✓ |
| D7 | 40 | 2 | LCD_R4 | 24 | ✓ |

Board 2 batch 3: 17 to 24 pulses, touch, both links, two red lines

Batch 4:

| Ch | Header | GPIO | Signal | Pulses | Seen |
|---|---|---|---|---|---|
| D0 | 17 | 11 | LCD_G6 | 25 | ✓ |
| D1 | 20 | 14 | LCD_B4 | 26 | ✓ |

Board 2 batch 4: 25 and 26

Pin walk on board 3. Only nine pins: the eight R-2R bits and LINK2's
receive line. The DAC bits are the ones that have to be exact, since
all eight get written in one store to GPIO_OUT later. All eight matched,
and LINK2_RX on the RX pad showed its 9 pulses. Pin walk done on all
three boards, 61 pins, no mismatches.

| Ch | Header | GPIO | Signal | Pulses | Seen |
|---|---|---|---|---|---|
| D0 | 4 | 4 | DAC_D0 | 1 | ✓ |
| D1 | 5 | 5 | DAC_D1 | 2 | ✓ |
| D2 | 6 | 6 | DAC_D2 | 3 | ✓ |
| D3 | 7 | 7 | DAC_D3 | 4 | ✓ |
| D4 | 12 | 8 | DAC_D4 | 5 | ✓ |
| D5 | 15 | 9 | DAC_D5 | 6 | ✓ |
| D6 | 16 | 10 | DAC_D6 | 7 | ✓ |
| D7 | 17 | 11 | DAC_D7 | 8 | ✓ |
| D0 (batch 2) | 42 (RX) | 44 | LINK2_RX | 9 | ✓ |

Board 3 batch 1: the eight DAC bits, 1 to 8 pulses

Board 3 batch 2: LINK2_RX, 9 pulses

## 2026-09-23

Wrote the SPI side for the ADCs: GP-SPI2 set up straight from its
registers, no driver. Clock on, pins on the IO MUX, 80 MHz module clock
divided down, mode 1, 16 clocks per frame, single or dual line. The
fastest legal clock is 26.67 MHz (80 MHz / 3), since /2 would be 40 and
the ADS7883 tops out at 32 at 3.3 V.

Speed test is written too: times 10,000 frames on the cycle counter for
five settings and holds each for 2 s so the analyzer can catch it.
Nothing plugged in yet, the analyzer run is next.

## 2026-09-24

Ran the speed test on board 1. JTAG flashing kept failing in OpenOCD,
so flashed over UART on COM7 instead.

First run tripped the task watchdog: the 2 s hold loop spun and IDLE0
never ran. It yields every 500 frames now. The result lines also went
missing until I added a 10 ms delay after unmasking interrupts, plus
fflush.

| SCLK | Mode | Lines | Cycles/frame | ns/frame | kSa/s |
|---|---|---|---|---|---|
| 10 MHz | 1 | single | 525 | 2188 | 457 |
| 10 MHz | 1 | dual | 525 | 2188 | 457 |
| 26.67 MHz | 0 | single | 261 | 1088 | 919 |
| 26.67 MHz | 1 | single | 261 | 1088 | 919 |
| 26.67 MHz | 1 | dual | 261 | 1088 | 919 |

At 26.67 MHz the 16 clocks take 600 ns, so about 490 ns of each frame
is overhead from the CPU starting each frame. DMA fixes that later.
Dual line costs nothing, so it's Plan B: one SCLK and CS for both ADCs,
CH1 on GPIO13, CH2 on GPIO11.

Speed test output on the monitor

Analyzer on board 1, 24 MHz sample rate:

| Analyzer | GPIO | Signal |
|---|---|---|
| D0 | 12 | SCLK |
| D1 | 10 | CS |

Analyzer wired to board 1

Five frames back to back

10 MHz: CS period 2208 ns, matches the 2188 from the cycle counter.
16 clocks per frame.

10 MHz block, 16 clocks inside one CS low

26.67 MHz: CS period 1084 ns, matches 1088. The clock itself aliases at
24 MHz sampling, so the CS period is the proof here, not the edges.

26.67 MHz block, CS period

The analog rail. MCP1700 on the breadboard, 1 uF ceramics for
C1 and C2 from the MLCC kit, jumper wire for R1. Nothing else on
+3V3_A yet.

+5V comes from the ELEGOO breadboard power module for now instead of
board 1's 5V pin, so the USB backfeed check is skipped. Its USB-C input
only gave 4.648 V (passthrough plus the drops along the way). The
barrel jack goes through the module's own regulator and gives 4.987 V,
so that's what I'm using.

| Node | Reading |
|---|---|
| +5V_A (VIN) | 4.987 V |
| +3V3_A (VOUT) | 3.314 V |

3.314 V is 0.4% high, well inside the MCP1700's +/-3% spec.

+5V_A from the barrel jack

+3V3_A at the MCP1700 output

The 2.2 V reference. R2/R3 (10k/20k) off +3V3_A with C3 on
the midpoint, U2A as a unity-gain buffer, C4 right on pin 8. U2B is
parked as a follower with its input on GND, same as the schematic.

| Node | Reading |
|---|---|
| Divider (pin 3) | 2.214 V |
| VREF_2V2 (pin 1) | 2.214 V |

Expected 3.314 x 20k/30k = 2.209 V, so 5 mV off, inside 1% resistor
tolerance. Pin 1 matches pin 3, so the buffer adds nothing.

VREF_2V2 at the buffer output

Prep for the front end: the parts that don't fit a breadboard.

BNCs (Superbat panel mount) got jumper wires soldered on: centre pin for
signal, solder lug for ground. Continuity centre to jack pin and lug to
barrel beep, centre to shell reads OL.

BAV99s are SOT-23-3, so they went on the adapter boards. Tiny and
sloppy without proper tools, but continuity passes. The adapter
silkscreen doesn't match the part:

| BAV99 pin | Job | Adapter pad |
|---|---|---|
| 1 | lower anode, to GND | 6 |
| 2 | upper cathode, to +3V3_A | 2 |
| 3 | common, to JCT | 4 |

One of the two has pins 2 and 3 bridged. That shorts the upper diode
and ties JCT straight to +3V3_A, so it's not going in until the bridge
is cleaned up.

BNC with soldered leads, continuity

BNCs and BAV99 adapters, continuity

BAV99s on their adapters

CH1 front end on the breadboard: R4 750k, R5 250k to VREF_2V2, BAV99
clamp, U3A buffer. Trimmers and the ADC filter stay off for now. Output
measured at U3 pin 1.

| Input | Expected | Measured |
|---|---|---|
| Nothing connected | 2.21 V (no current, so it sits at VREF) | 2.2 V |
| IN to GND | 1.66 V (0.75 x VREF) | 1.66 V |

Input open, output at VREF

Input grounded, output at the 1.66 V offset

CH2 front end, same circuit: R7 750k, R8 250k to VREF_2V2, the second
BAV99, U4A buffer. Output measured at U4 pin 1.

| Input | Expected | Measured |
|---|---|---|
| Nothing connected | 2.21 V | 2.21 V |
| IN to GND | 1.66 V | 1.66 V |

Both channels match each other and the math.

CH2 input open, output at VREF

CH2 input grounded, output at the 1.66 V offset

## 2026-09-25

Front panel on board 1: three LEDs and three buttons on their own
breadboard, wired to the board's headers.

Moved LED_TRIG from GPIO47 to GPIO2 first. There was no reason for it
to sit apart from the other two, and now the LEDs are on headers 39-41
right above the buttons on 36-38. Schematic, pin map and pin header
updated together.

| Part | GPIO | Header | Notes |
|---|---|---|---|
| LED_RUN (green) | 42 | 39 | 330R, active high |
| LED_TRIG (yellow) | 2 | 40 | 330R, active high |
| LED_ARM (red) | 1 | 41 | 330R, active high |
| BTN_RUN | 39 | 36 | to GND, internal 45k pull-up |
| BTN_SINGLE | 40 | 37 | to GND, internal 45k pull-up |
| BTN_GEN | 41 | 38 | to GND, internal 45k pull-up |

panel.c polls all six inputs (the three buttons plus the encoder
switches) every 1 ms and only takes a change after 20 scans in a row
agree, so bounce never gets through. Each clean press or release goes
on a FreeRTOS queue as an event. Polling instead of edge interrupts:
the 20 ms debounce sets the response time either way, and a bouncing
contact would fire dozens of interrupts per press.

The test prints every event and toggles an LED per button. One press
and one release per push, no doubles.

Panel test running, events on the monitor

[Video: buttons toggling the LEDs](docs/screenshots_videos/panel_buttons_leds_test.MP4)

Put the dual-line SPI decision into the schematic and pin map. Both
ADCs now share one clock and one chip select on SPI2's IO MUX pins, and
CH2's data comes in on GPIO11 (FSPID) next to CH1's on GPIO13 (FSPIQ).
The old second bus on GPIO15-17 is gone, and so is R11: one 10k pull-up
on the shared CS covers both converters.

That freed three pins right where the encoders were scattered, so the
encoders moved too. All nine encoder lines now sit on headers 4-12, one
knob after another.

| Signal | Was | Now | Header |
|---|---|---|---|
| ADC_SCLK | 12 (CH1) + 15 (CH2) | 12 | 18 |
| ADC_CS | 10 (CH1) + 17 (CH2) | 10 | 16 |
| CH1_SDO | 13 | 13 | 19 |
| CH2_SDO | 16 | 11 | 17 |
| ENC2_B | 8 | 15 | 8 |
| ENC2_SW | 9 | 16 | 9 |
| ENC3_A | 18 | 17 | 10 |
| ENC3_B | 21 | 18 | 11 |
| ENC3_SW | 38 | 8 | 12 |

Spares now 9, 14, 21, 38, 47. Nothing was wired to the old pins yet, so
this is paper only, the encoders get checked on the new pins when they
count.

Three EC11 encoders on the panel breadboard, on the new pins (headers
4-12). Each one: A and B to their GPIOs, the middle pin C to GND, push
switch between its SW GPIO and GND. Internal pull-ups, no extra parts.

The decoder is a 16-entry table indexed by the last and current A/B
state, run in the same 1 ms scan as the buttons. A legal step gives +1
or -1, no change or an illegal jump gives 0. Contact bounce toggles one
line back and forth, which reads as +1, -1, +1, -1 and cancels, so
there's no separate debounce. Four steps make one detent on these
(one full A/B cycle per click), and only whole detents become events.

One click prints enc1 +1, back prints enc1 -1, on all three knobs.
The knob presses come through the button code as ENC1-3 press/release.

Encoders, buttons and LEDs on the panel breadboard

[Video: turning and pressing the knobs](docs/screenshots_videos/panel_encoders_test.MP4)

## 2026-09-26

Soldered both ADS7883s onto SOT23-6 adapters. Took about four hours,
with no magnifier, no clamps or helping hands, and 0.8 mm solder, which
is too thick for 0.95 mm pitch. Lost two chips along the way, two made
it, which is what the design needs.

What finally worked: tin one corner pad only, hold the chip with
tweezers, reflow that blob to tack one leg, then do the opposite
corner, then the rest. Once one leg is down the chip stops moving.
Headers went on first with the breadboard as a jig, chip after.

Checks on both boards, nothing powered yet:

- Continuity from every chip leg to its header pin: all six pass.
- Adjacent pins shorted: none.
- Orientation from the diode test on the first chip: pin 2 conducts to
  every other pin with the red probe on it, so it's GND and the chip
  is the right way round.

Next time: 0.5 mm solder, tacky flux paste and fine tweezers.

Soldering setup

First ADS7883 on its adapter, next to a bare SC70 one

Both ADS7883 adapters, continuity checks

Wired both ADCs into the front ends. U6 on CH1, U7 on CH2, sharing
SCLK (IO12) and CS (IO10), data on IO13 and IO11. R6/R9 are two 330R in
parallel (165R) instead of 150R, still under the ADS7883's 200R source
limit. C8/C9 and C13/C14 (2.2 nF) are on each ADC input. Trimmers and
BNCs still off, IN is a jumper for now.

Both chips are soldered 180 degrees round on their adapters, so the
silkscreen is off by three: chip pins 1-6 are silk 4, 5, 6, 1, 2, 3.
Wired by chip pin, not silkscreen.

First read with the single-line test: code 0.0 on every frame, which
prints as -6.644 V at the BNC. The firmware checks out, and 0 is what
the ADC should report for 0 V in, so the problem is upstream. VREF
wasn't connected to the dividers at first, with that fixed, the R4/R5
junction reads 1.63 V as expected, but VIN at the ADC was still near
0 V. Swapping the two ADCs gave the same result. Still tracing.

Setup for the first ADC read

Monitor stuck at code 0

Found one: SCLK and CS were swapped on the breadboard. The ADC was being
clocked on its CS pin and selected by the clock, so it never produced a
real frame. With them swapped back the codes move off zero (about 25,
with some frames near 88), so the SPI link is alive. Still well under
the ~2000 expected for 1.63 V in, so VIN is next.

Codes off zero after the SCLK/CS fix

Printed every raw frame instead of the average. About a third of the
frames were wrong, and always the same way: the good code shifted left
one bit (2059 came back as 22). The ADC was one clock ahead, like it
counted an extra SCLK edge right after CS fell.

Put the logic analyzer on it. Two things in the captures: the PulseView
decoder has to match the ADC (mode 0, CS active-low) or it shows garbage
of its own, and the shifted frames were really on the wire. On a bad
frame both SDO lines flick high for about 40 ns after the first falling
edge, then drop, so both chips stepped twice on one edge.

Decoder in mode 1: frames shifted

Decoder in mode 0: good and shifted frames mixed

Tried, in order:

- SPI mode 1 to mode 0. No real change.
- One clock of CS setup before the first SCLK. Bad frames went from 35%
  to 9%.
- 50R in series with SCLK. Worse, about half the frames bad.
- New jumper, rerouted. Still about 40%.
- Unplugged the logic analyzer. Zero bad frames.

The analyzer was the problem. Its leads on the shared SCLK line plus its
ground going back through USB were enough to make both ADCs double
count a clock edge. The 9% run was the only one taken before it was
clipped on. Lesson: the probe is part of the circuit.

With it off: clean at 4 MHz and at 10 MHz, both channels. Checked CH2 by
moving its SDO wire onto IO13 and touching its input to VREF (code jumps
to about 2720). Kept the CS setup delay, dropped the resistor.

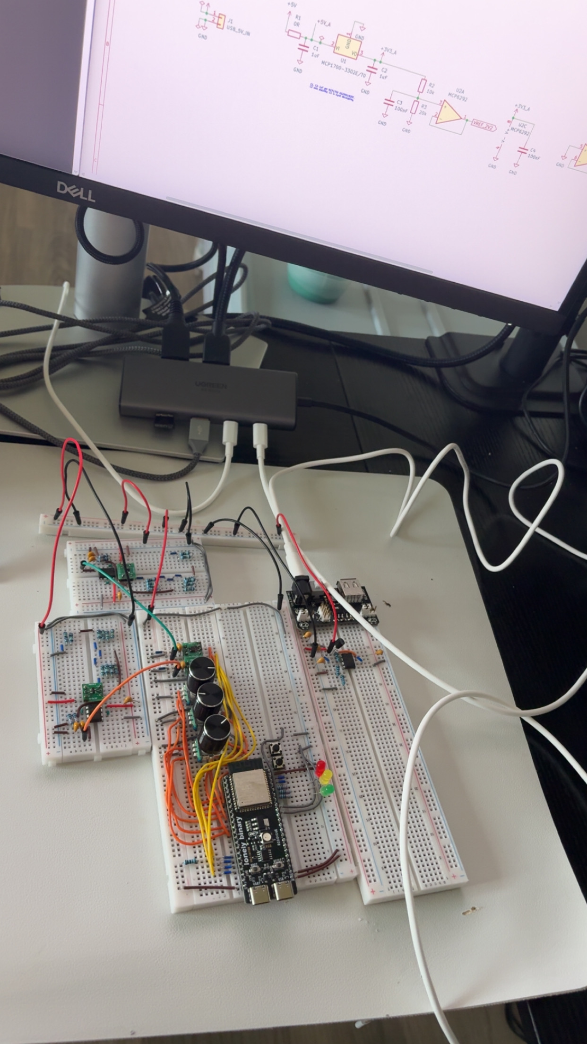
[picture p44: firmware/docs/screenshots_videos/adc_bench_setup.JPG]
Bench while chasing it


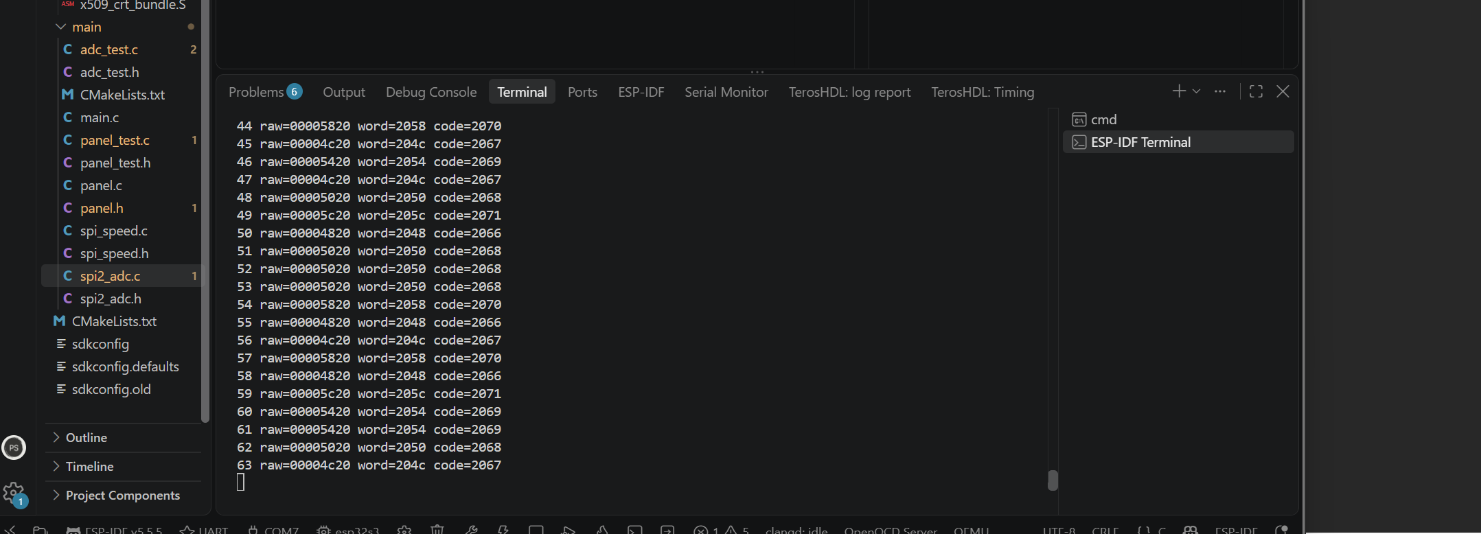
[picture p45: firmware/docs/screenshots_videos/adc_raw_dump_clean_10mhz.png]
Raw frames at 10 MHz, all good


Last bit was calibration. With IN grounded the ADC reads 2067, which is
1.672 V against a 3.314 V supply, not the 1.661 V I'd assumed. Set the
offset to the measured value and the BNC reading sits at 0.001 V,
steady to one code.

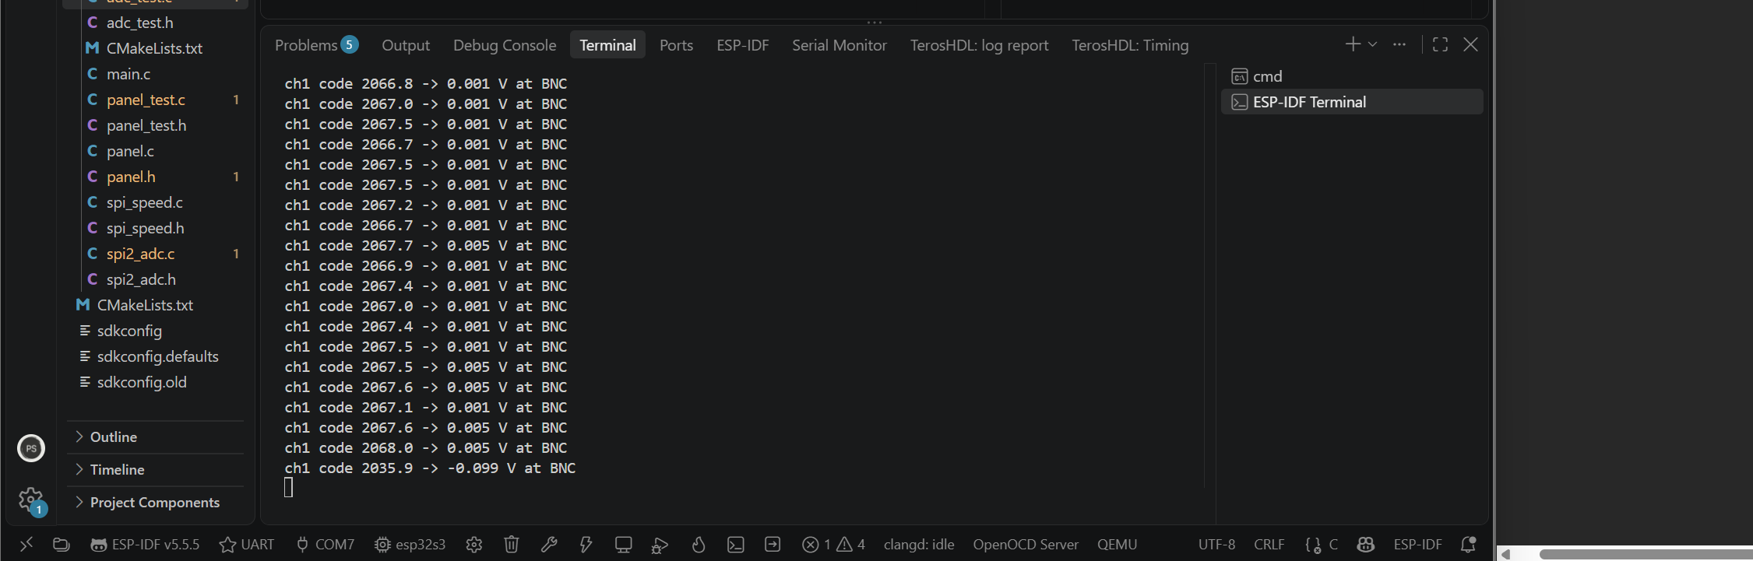
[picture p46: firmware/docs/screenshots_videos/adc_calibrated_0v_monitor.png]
Calibrated: 0.001 V at the BNC with IN grounded


## 2026-09-27

Noise floor at full speed. SCLK at 26.67 MHz, IN grounded, 16384
samples per run, both SPI modes back to back.

Both modes were clean over about 100k samples, no bit-slips, and the
noise is the same: about 4 codes rms, 13 mV at the BNC. Went with mode 1
anyway. At this clock the ADC's data can show up 20 ns after the falling
edge, and mode 0 samples 18.75 ns after it, so mode 0 has negative
worst-case margin on paper. Mode 1 samples a full clock later.

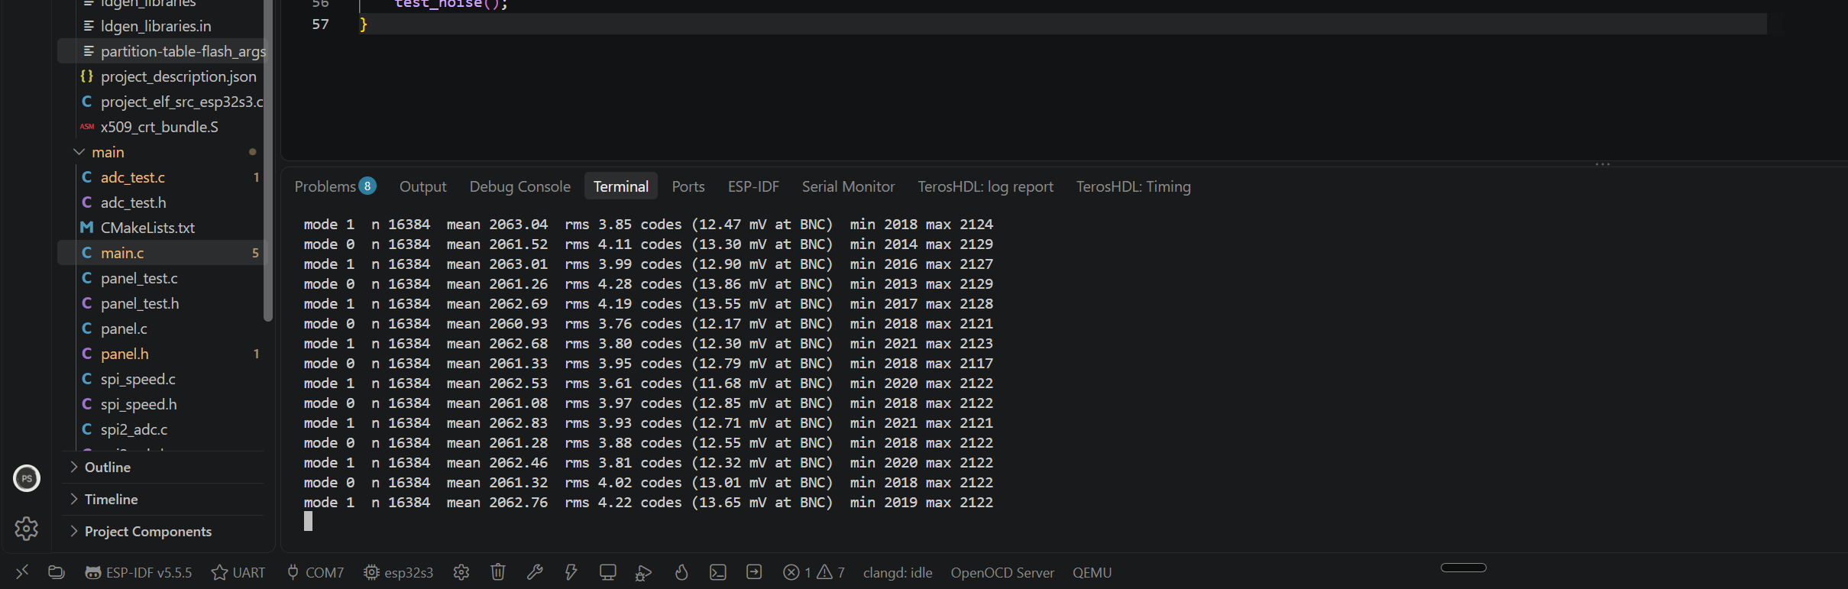
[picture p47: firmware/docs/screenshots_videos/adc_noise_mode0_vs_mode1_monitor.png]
Mode 0 and mode 1 side by side on the monitor


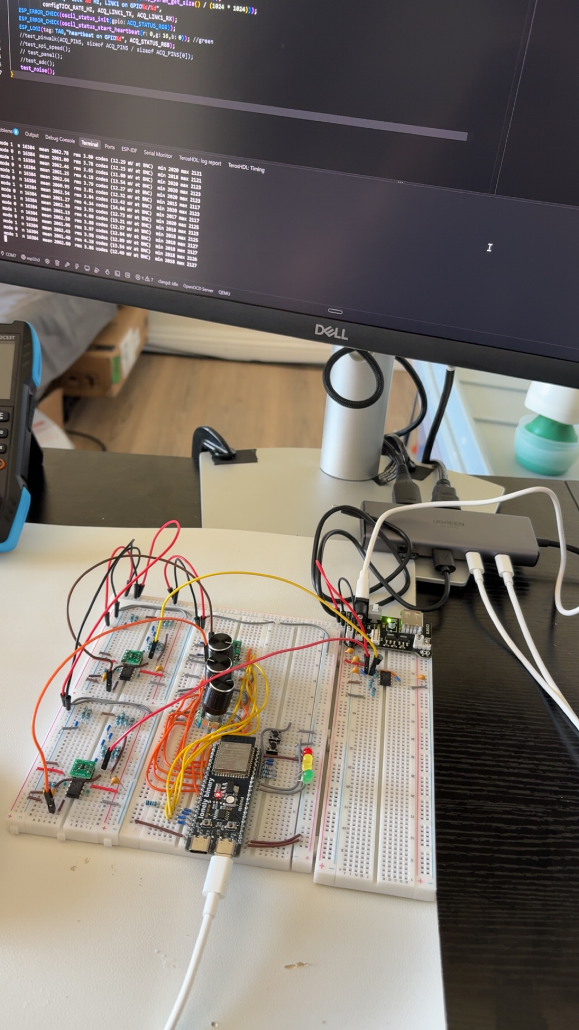
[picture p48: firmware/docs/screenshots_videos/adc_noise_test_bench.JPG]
Bench during the noise test


Dumped one run to the PC for a histogram. First try came back with a
third of the lines missing and one corrupted value (061 instead of
2061) that dragged the rms to 19 codes. The board was printing faster
than the USB console could drain. A 10 ms pause every 128 lines fixed
it, and the capture script now rejects anything short or malformed.

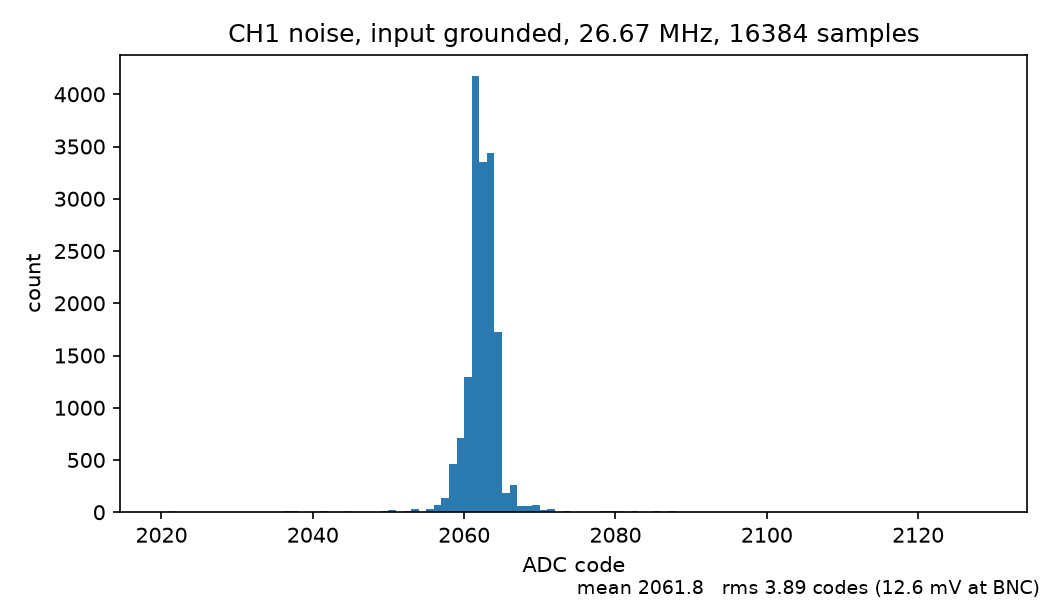
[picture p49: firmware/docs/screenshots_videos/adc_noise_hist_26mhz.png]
Histogram, 16384 samples, IN grounded


Most samples sit within 4 codes of the mean. The rms is pulled up by a
few lone samples 40 to 60 codes out, which looks like pickup on the
breadboard rather than the ADC. The filter as built (165R and 4.4 nF)
puts the corner at about 219 kHz.

The mean at 26.67 MHz is about 2062, 5 codes lower than at 10 MHz, so
the offset calibration has to be done at the speed it runs at.

Both channels in one read. The two ADCs share SCLK and CS, and CH2's
data comes in on the second SPI data line, so one 16-clock frame
brings in 32 bits with the two channels interleaved bit by bit. A
five-step shift-and-mask pulls every other bit back together.

Moved the ADC frame decoding into its own header with no ESP-IDF
includes, so the same code builds on the PC. The host test interleaves
two known words the way the hardware does and checks the fast split
against a plain bit-by-bit loop on 10,000 random pairs.

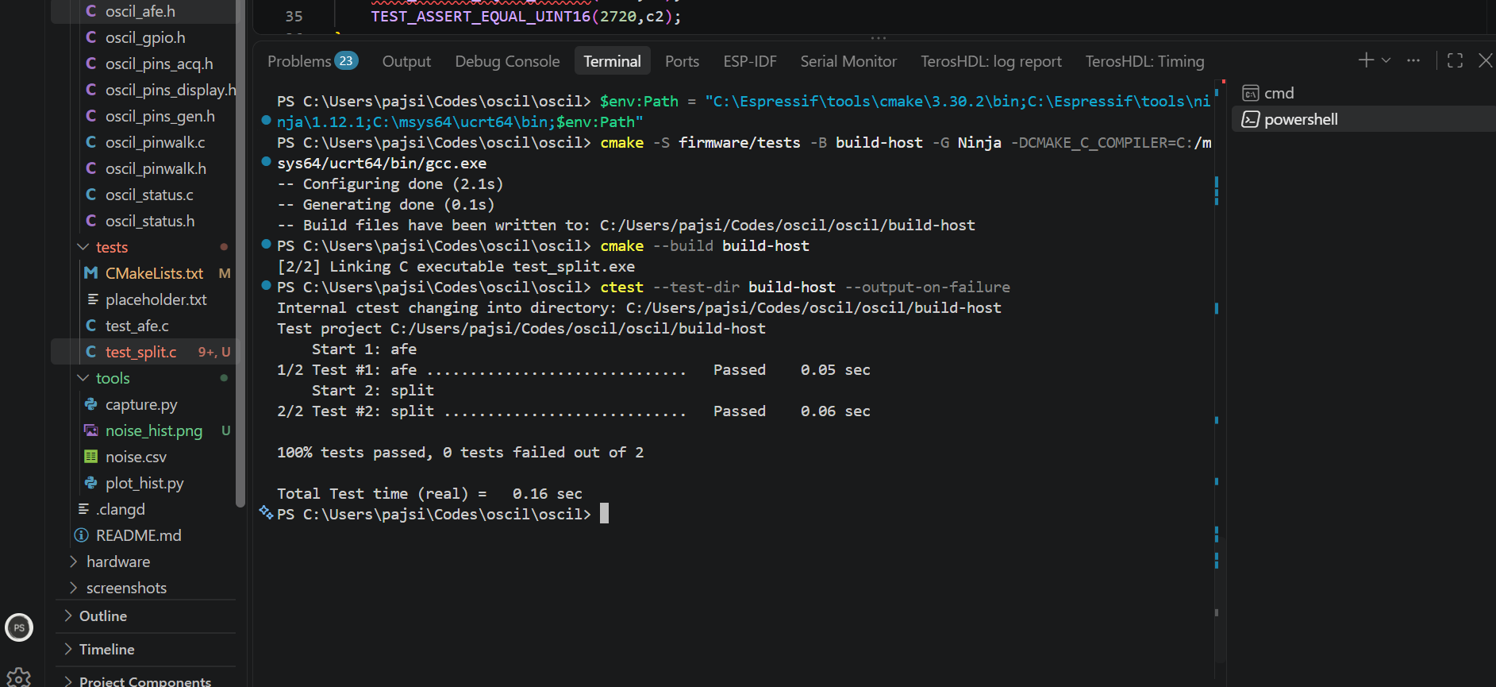
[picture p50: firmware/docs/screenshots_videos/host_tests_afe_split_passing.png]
Host tests passing on the PC


On the board, both inputs grounded at 26.67 MHz: CH1 about 2062, CH2
about 2069. The 7-code gap (about 24 mV at the BNC) is steady, so it's
an offset between the two front ends, and it gets calibrated per
channel. CH1 in the dual read matches CH1 read on its own at the same
speed, so the channels aren't swapped.

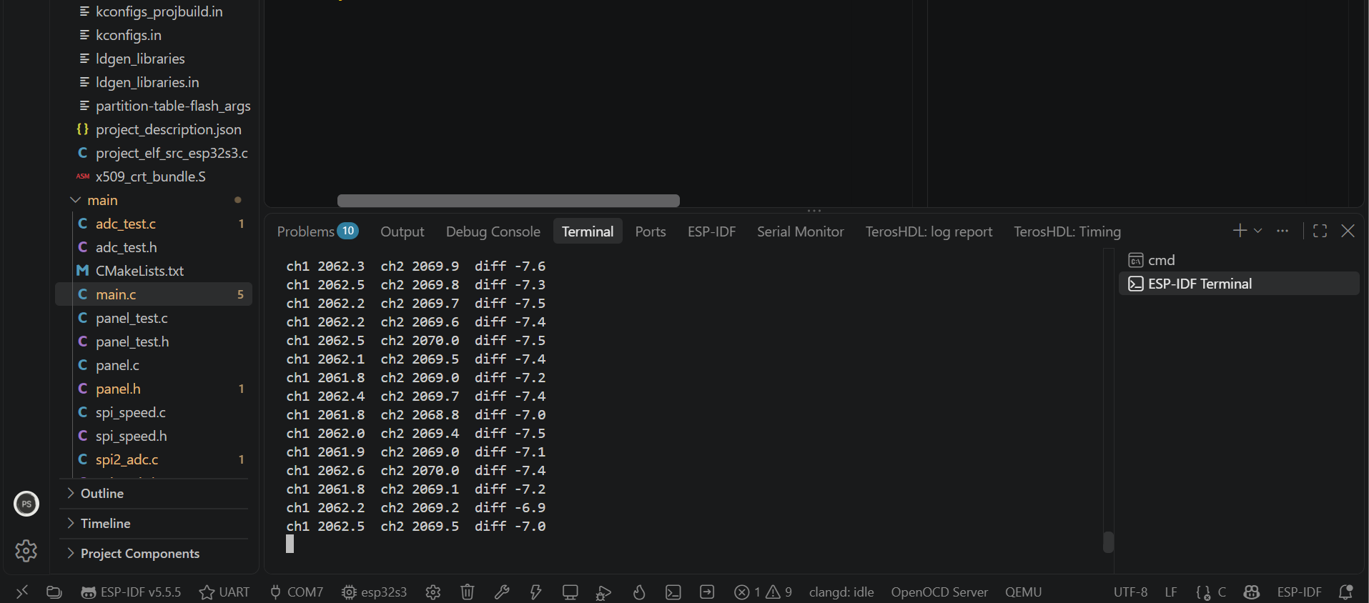
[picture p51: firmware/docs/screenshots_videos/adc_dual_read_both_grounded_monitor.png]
Both channels from one frame, inputs grounded


Burst capture with DMA. Until now every sample was the CPU starting an
SPI frame and waiting for it. Now the SPI block and the DMA engine run
a whole burst on their own: a list of 3200 small segments, each one a
full ADC frame, with the gap between frames set by a hardware counter
in 12.5 ns steps. The CPU starts the burst, sleeps, and gets one
interrupt at the end.

To check the timing I needed a signal I trust, so board 1 makes its
own: a 1 kHz square from the LEDC peripheral on a spare pin, jumpered
into CH1's input. Samples per period tells you the real sample rate.

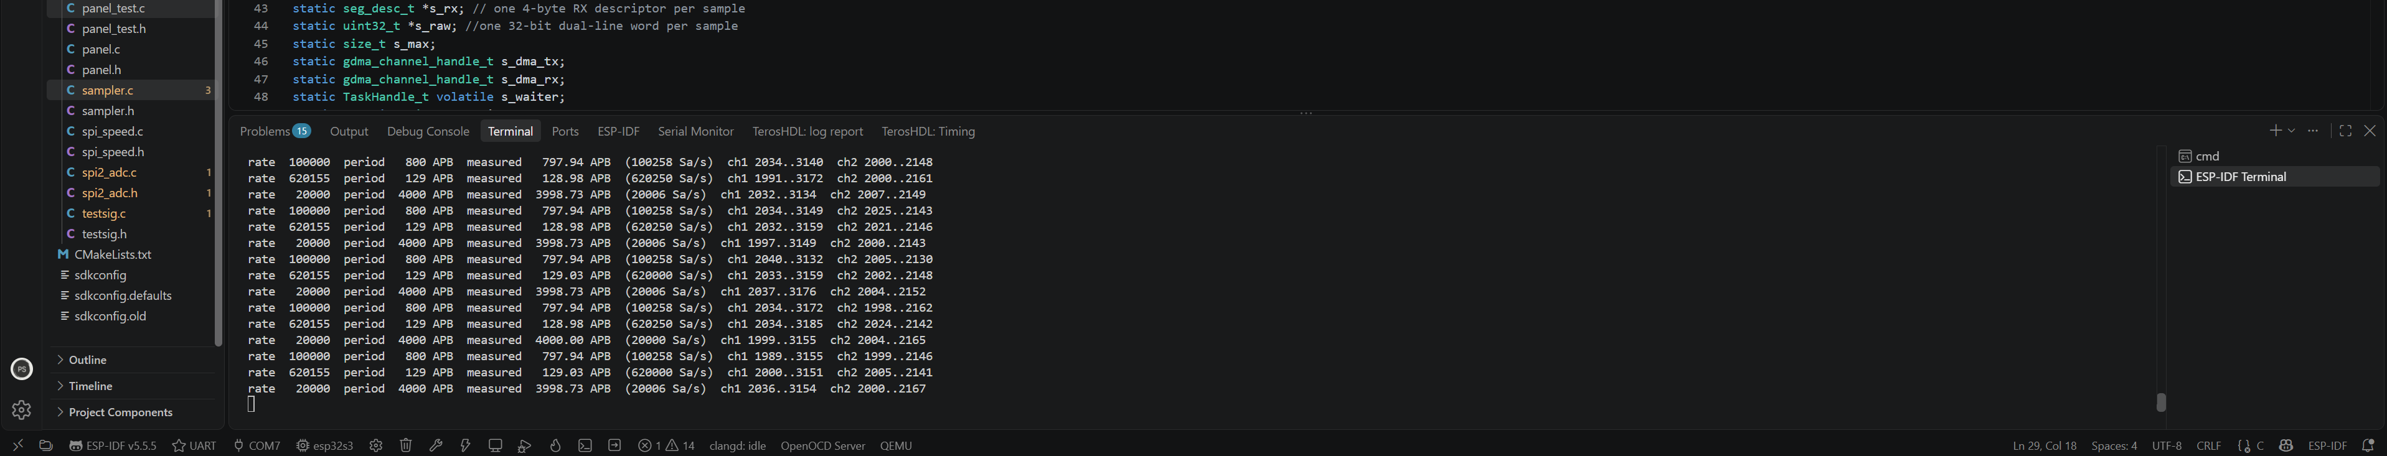
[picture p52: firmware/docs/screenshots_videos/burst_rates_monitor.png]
Burst rates on the monitor


100 kSa/s measured 100.26 k, 20 kSa/s measured 20.01 k. The CS-low
part of each segment turned out much longer than the 51 clocks the
math gives, about 124 at the bus clock, because each segment also has
to load its setup from memory. That puts the ceiling at about 620 kSa/s,
not the 1.43 M I'd worked out on paper.

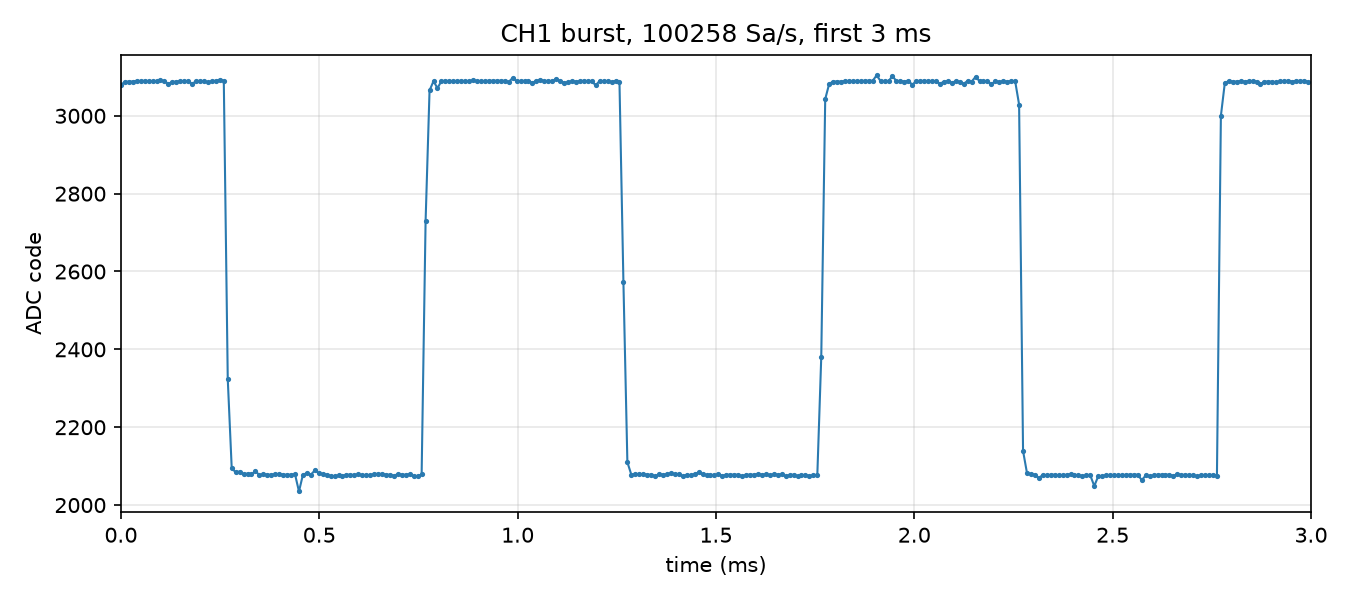
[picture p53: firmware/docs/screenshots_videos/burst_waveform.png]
First 3 ms of a burst at 100 kSa/s


The square comes through clean, about 2075 to 3090, with an edge
spread over one or two samples from the front end and the anti-alias
filter.

Reran the noise test with all of this wired up, and this time mode 0
fell apart at 26.67 MHz: minimums down around 20 and 35 to 50 codes
rms, the same bit-slip pattern as before. Mode 1 stayed at about 4
codes. Earlier both modes were clean, so mode 0 was sitting right on
the edge, which is exactly what the timing math said. Glad I went with
mode 1.

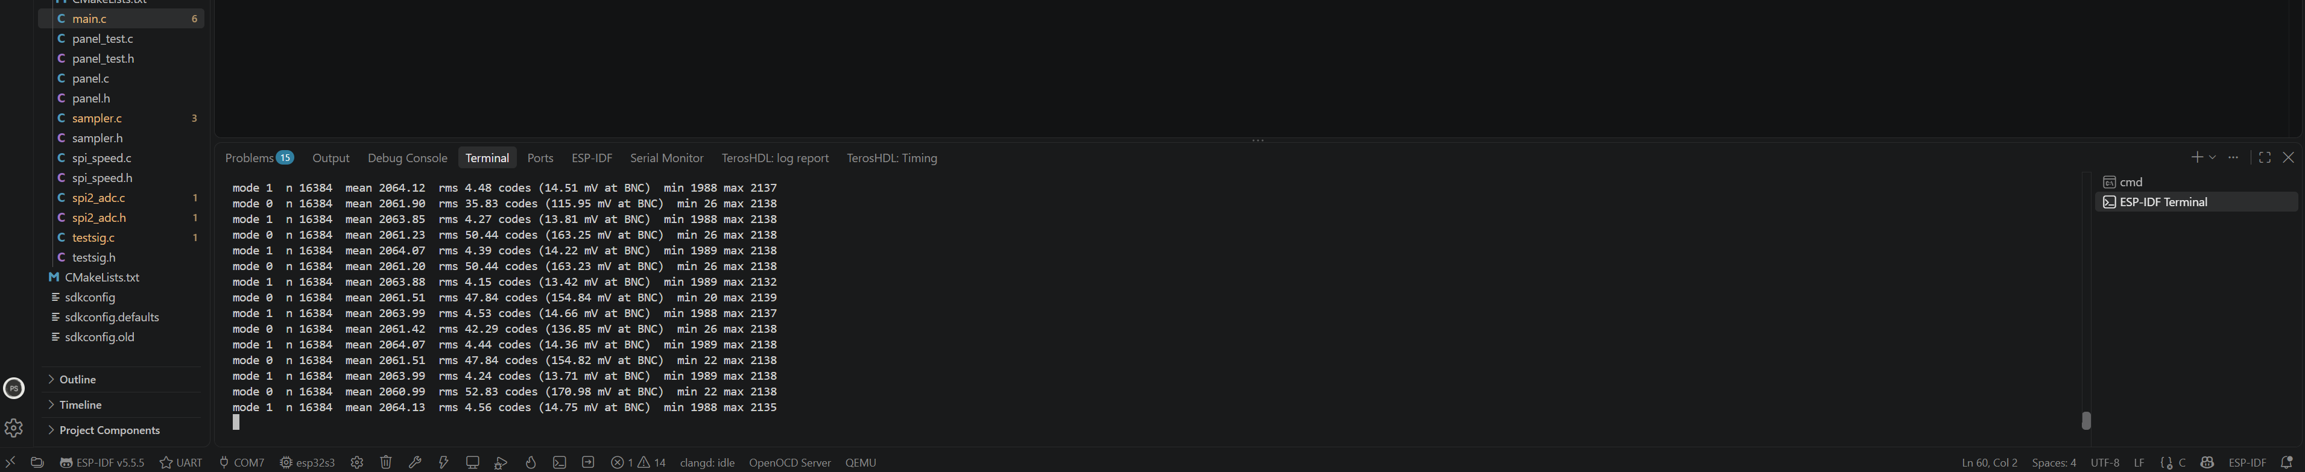
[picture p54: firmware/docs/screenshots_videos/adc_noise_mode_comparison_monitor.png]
Mode 0 slipping, mode 1 clean


Trigger. It scans a capture for the first point where the signal
crosses a level in the chosen direction, so a repeating waveform lands
in the same place every frame instead of sliding across the screen.
Two things make it usable on real signals: hysteresis, where the signal
has to drop clearly below the level before a rising crossing counts, so
noise sitting on the level can't fire it, and a sub-sample position,
interpolated between the two samples on either side of the crossing,
so the trace doesn't jump by a whole sample from frame to frame.

It's pure C, so it's tested on the PC: exact crossing on a clean sine,
a crossing 0.3 samples between two points, chatter at the level ignored,
falling edge, and a noisy sine that still triggers once per period. All
three host test suites pass.

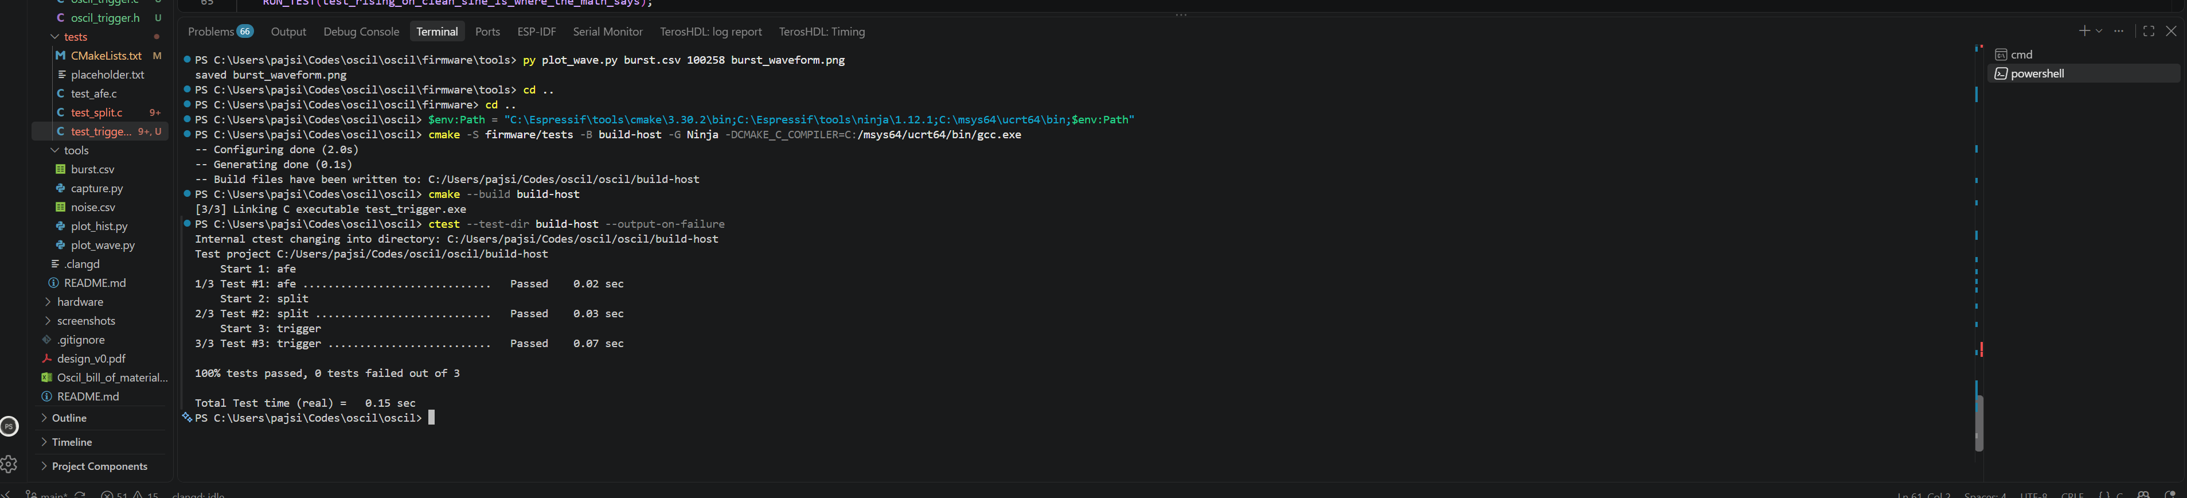
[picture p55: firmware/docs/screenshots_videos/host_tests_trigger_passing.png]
Host tests, trigger added


## 2026-09-28

Decimation. A capture has more samples than the screen has columns, so
each of the 800 columns has to stand for a group of samples. Averaging
or picking one sample per group would make a short glitch vanish. So
each column keeps both the lowest and the highest sample in its group,
and the screen draws a line between them. A spike one sample wide still
shows up.

Also pure C and host-tested: a one-sample spike survives, constant input
stays constant, 800 samples into 800 columns comes out unchanged, and a
ramp whose length isn't a multiple of 800 has every sample land in
exactly one column with no gaps. All four host test suites pass.

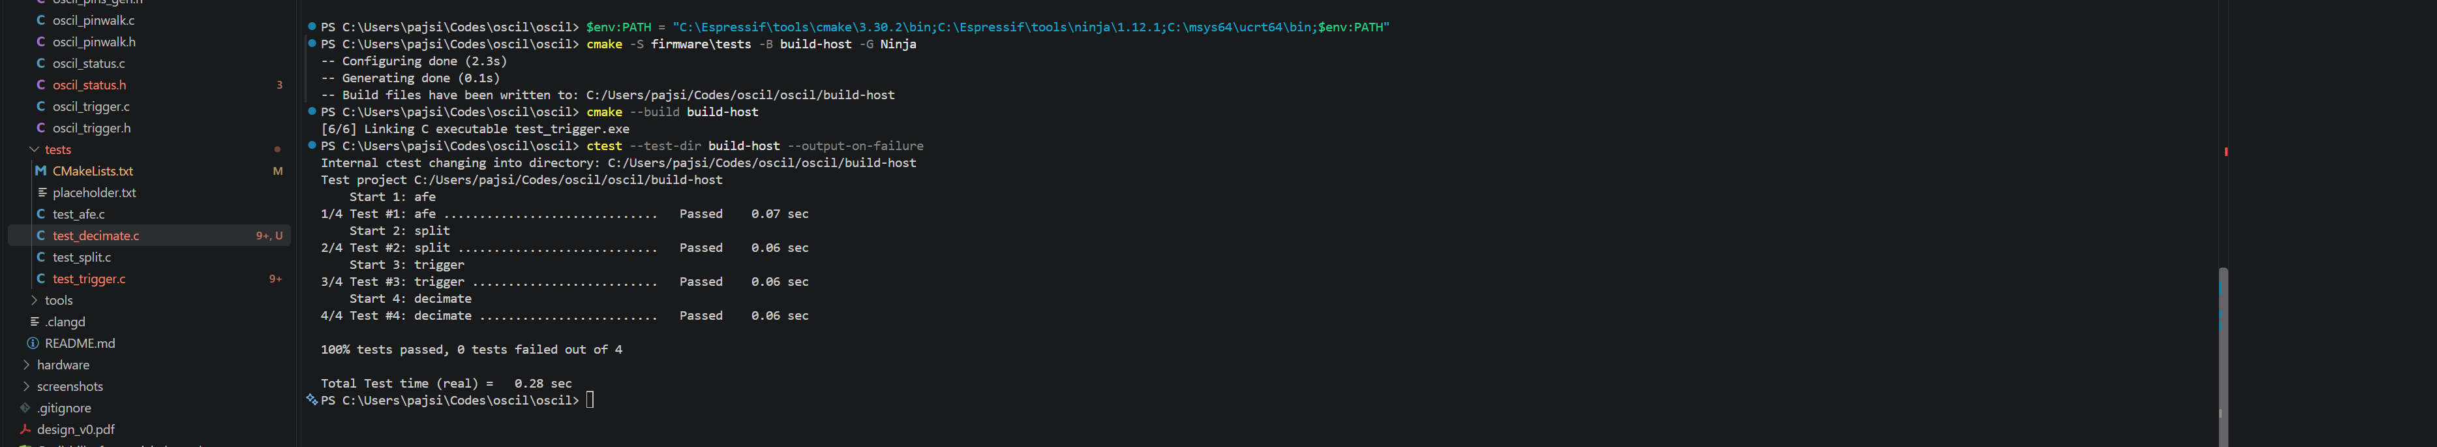
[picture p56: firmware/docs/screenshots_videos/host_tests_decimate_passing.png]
Host tests, decimation added


How the trigger and decimation work, drawn out: frames lining up on the
rising edge, hysteresis stopping noise at the level from firing it
again, the crossing placed between two samples, and min/max keeping a
one-sample glitch that averaging would shrink.

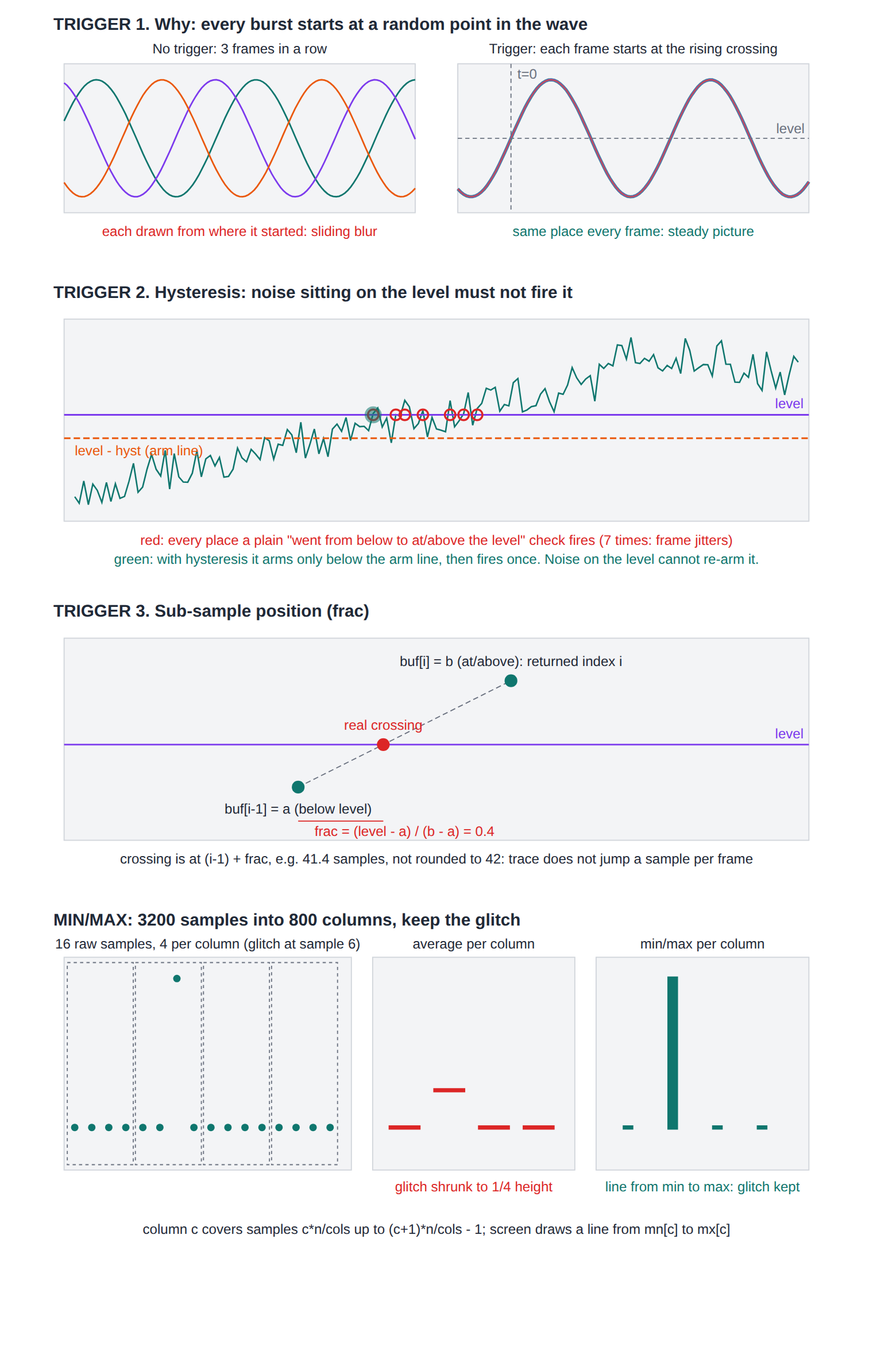
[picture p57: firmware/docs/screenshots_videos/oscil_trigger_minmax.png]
Trigger and min/max decimation explained


How capture actually runs. Each burst is one-shot: the CPU starts it,
the DMA fills 3200 samples on its own, the SPI block stops after the
last segment and fires one interrupt. Then the CPU triggers, decimates
and sends the frame, and only then starts the next burst. Whatever the
signal does in between is never recorded. That's dead time, and every
digital scope has it, the spec is called waveform update rate.

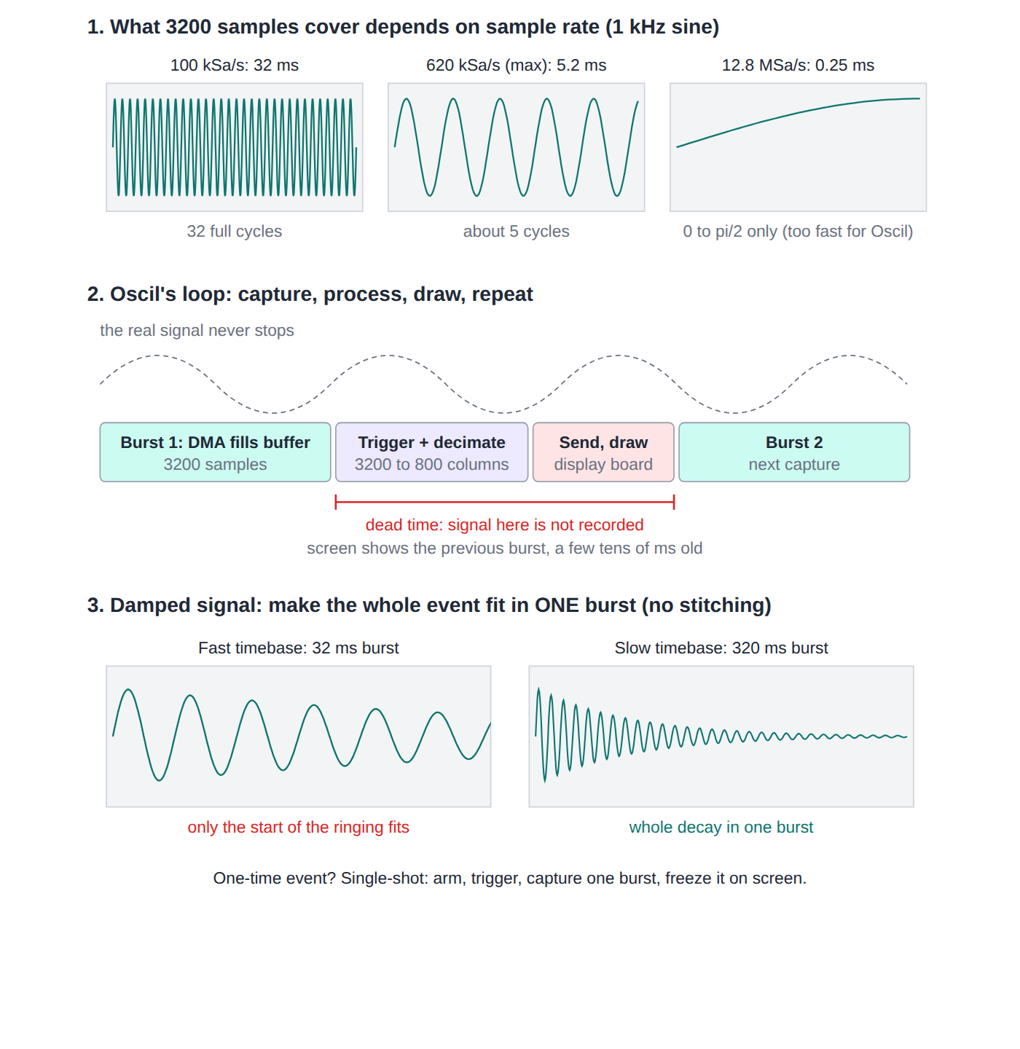
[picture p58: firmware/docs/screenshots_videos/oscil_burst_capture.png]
Burst coverage, the capture loop, and a damped signal


How much of the signal one burst holds depends on the ratio of signal
frequency to sample rate: cycles = f x 3200 / fs. A 1 kHz sine at
100 kSa/s is 32 cycles, at 620 kSa/s about 5. Frames are never stitched
together, so a one-time event like a damped oscillation has to fit
inside a single burst: slow the sample rate until it does, and use
single-shot so it's captured once and held.

Could the dead time go away? Checked the TRM (30.5.8.5): the segmented
transfer keeps going as long as each segment's CONF sets
usr_conf_nxt = 1, and my last segment clears it on purpose. Loop the
descriptor chains back to the start and set it everywhere, and it
should run as a continuous ring at the same data rate a burst already
proves. The catch is knowing when half the ring is full: the SPI
done interrupt only fires at the end, which never comes, and the GDMA
per-descriptor interrupt would fire on every sample. It would need a
timer or polling. And the screen only shows about 30 frames a second
out of roughly 190 bursts, so it only pays off for something like a
glitch search over every burst. Staying with one-shot for now, the
ring is a later experiment, untested.

Acquisition task. Board 1 now runs on its own: a FreeRTOS task pinned
to core 1 loops capture, trigger, min/max, and builds the frame that
will go to the display board. A settings struct under a mutex holds the
rate, trigger level, edge and source, and RUN/STOP/SINGLE, so the panel
buttons (and later the display board) can change it safely from other
tasks. AUTO mode shows an untriggered frame after three missed bursts,
so a flat line still draws instead of freezing.

Default rate is 320 kSa/s (500 us/div at 1600 samples). 800 kSa/s for
200 us/div was the plan on paper, but it's above the 620 kSa/s I
measured, so at full record length that setting is out.

With the 1 kHz bench signal on CH1: 70 frames/s, every frame triggered,
0 errors, about 2 KB of the task's 4 KB stack left. One burst is
3200 samples at 320 kSa/s, 10 ms, so the ceiling is 100 frames/s, 70
means about 4 ms per frame of trigger, decimation and re-arming the
burst, roughly 30% dead time. RUN stops and restarts with all three
LEDs following, SINGLE captures one frame and holds.

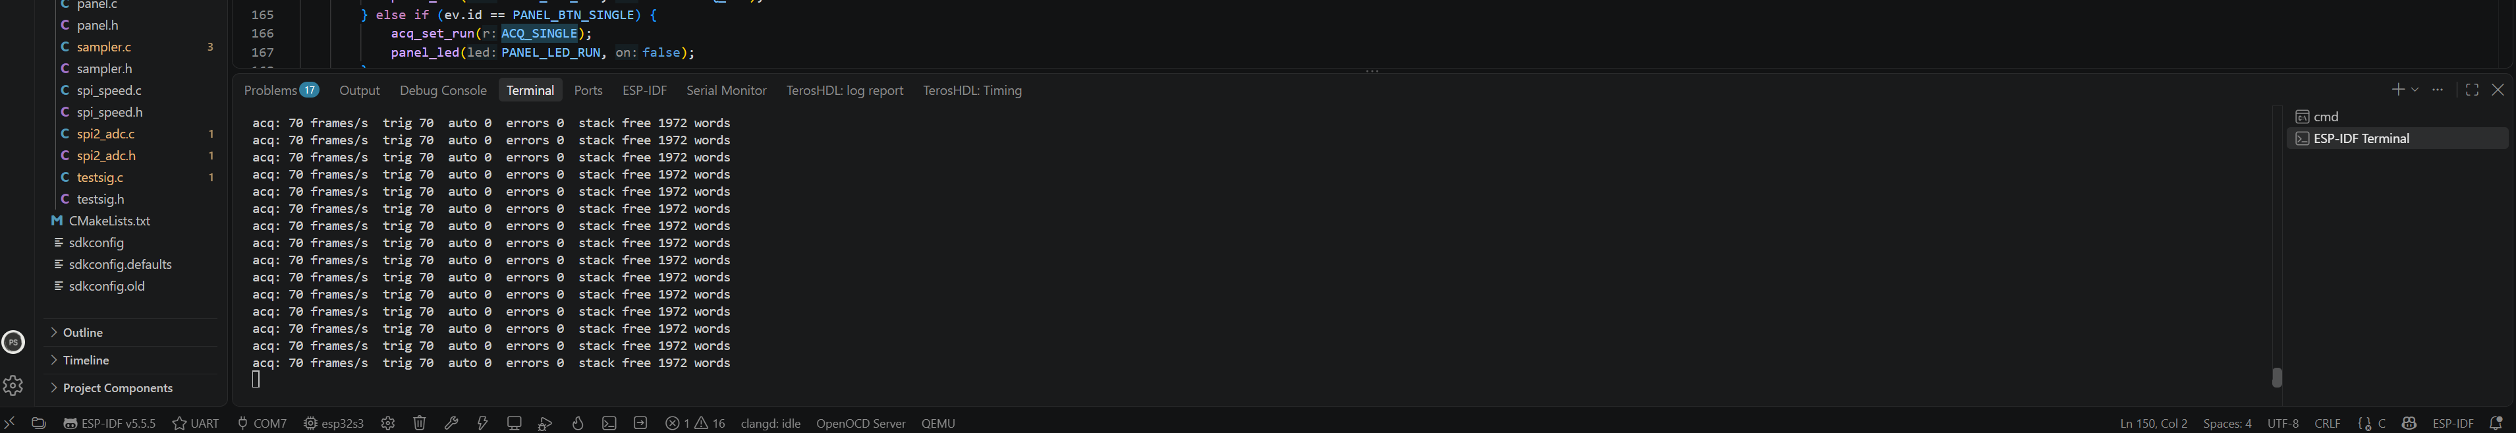
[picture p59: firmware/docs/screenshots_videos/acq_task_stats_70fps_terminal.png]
Stats line: 70 frames/s, every frame triggered, no errors


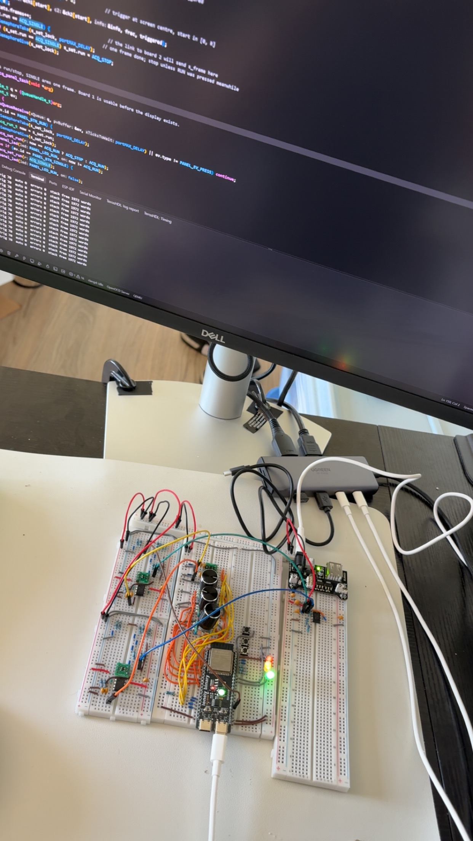
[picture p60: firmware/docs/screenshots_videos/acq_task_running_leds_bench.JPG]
Board 1 running on its own, RUN, TRIG and ARM lit


Link protocol. Board 1 has to send frames to board 2 over a UART, and a
UART only moves bytes: no message boundaries, no error check, no way to
find your place if you start listening mid-stream. Each message is now
type, sequence number, length, payload and a CRC-16, then COBS-encoded
so the byte 0x00 never appears inside it, then a single 0x00 to end it.
The receiver collects bytes until 0x00, decodes and checks the CRC,
after garbage it just waits for the next 0x00 and is back in sync. A
jump in sequence number counts as a lost frame. Pure C, host-tested: the
published CRC check value, COBS at its awkward lengths (253, 254, 255),
a flipped bit caught, garbage ignored, a missing frame counted.

UART driver, written from the registers: UART1 on GPIO43/44 through the
GPIO matrix, an interrupt handler and a ring buffer each way. Tested in
loopback, a 220R from TX back to RX on board 1, sending frames of random
length up to 7 KB at 2 Mbaud. 15,600 frames in about 4.5 minutes, every
one intact, zero CRC, length, framing, overflow or dropped-byte errors.
About 55 frames a second of 3.6 KB average, so the wire is running at
full speed. The ring buffer is host-tested too, and all six host test
suites pass.

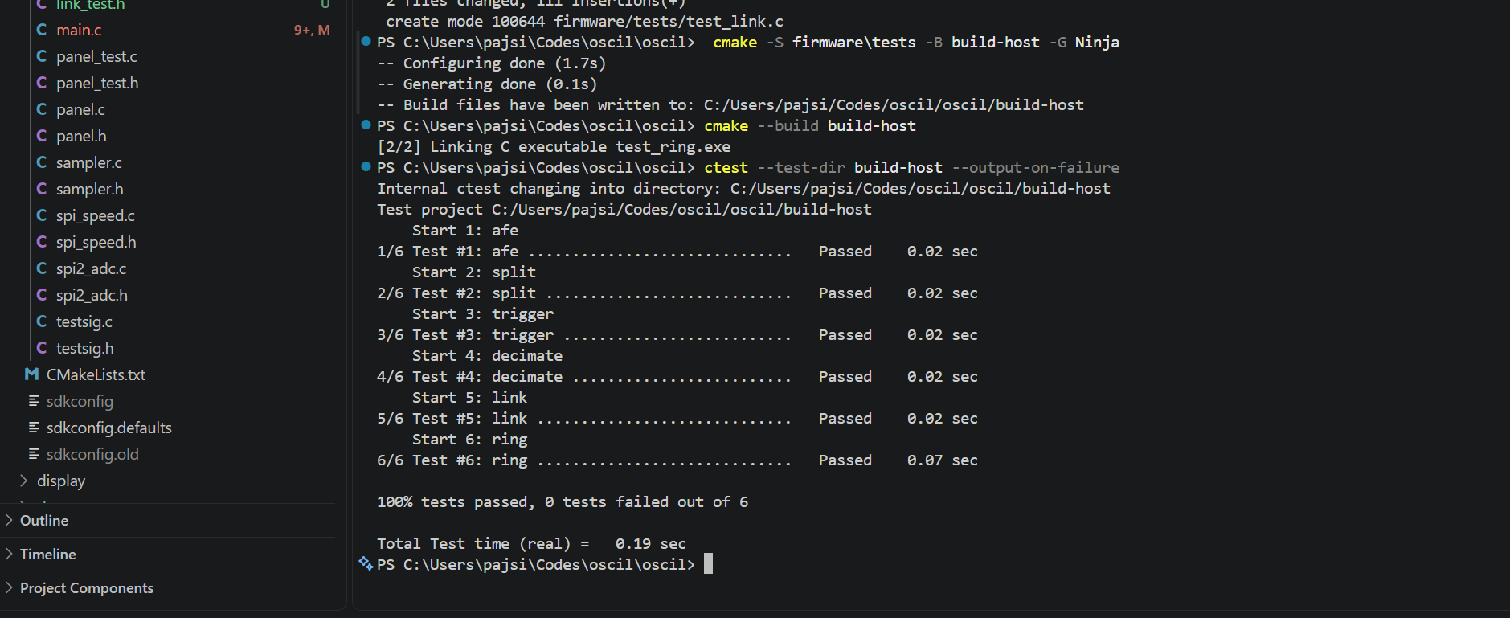
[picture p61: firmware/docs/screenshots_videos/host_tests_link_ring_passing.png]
Six host test suites passing


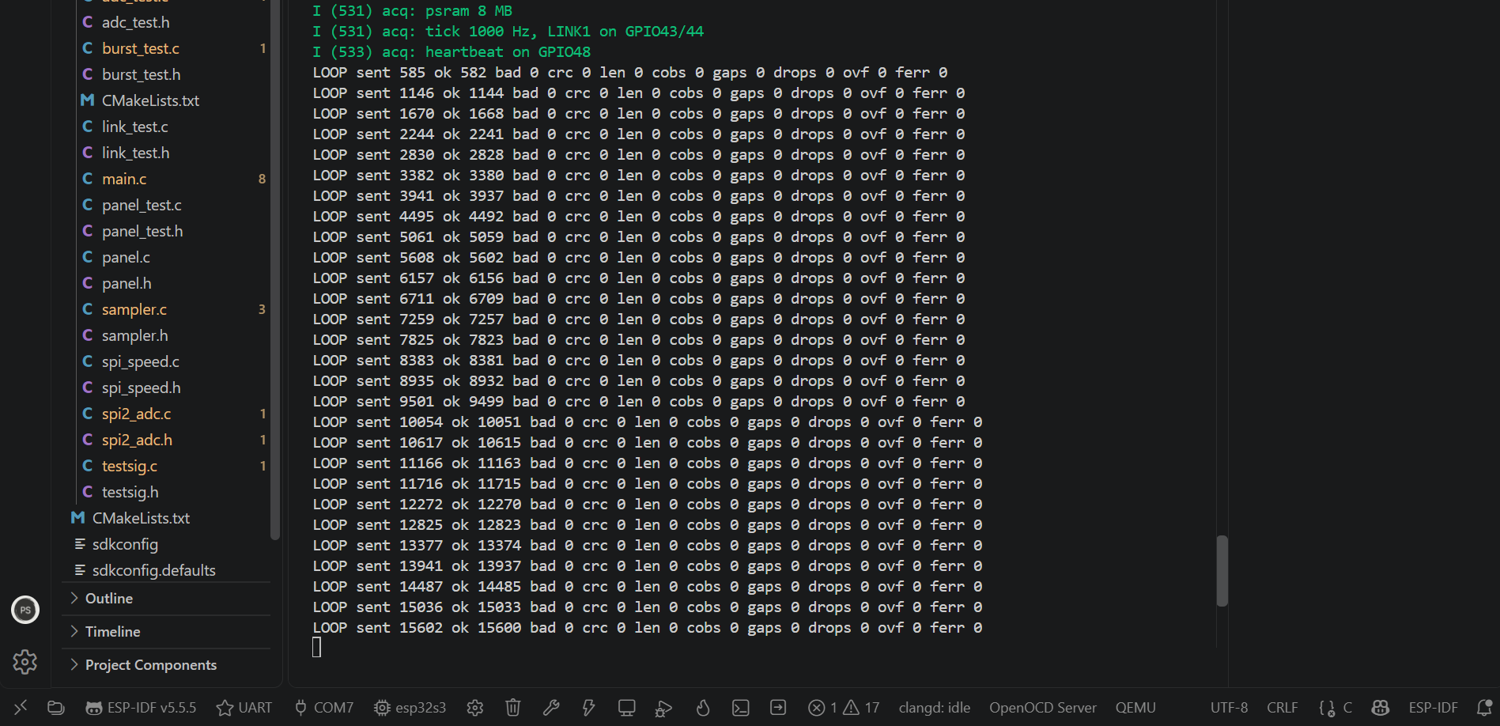
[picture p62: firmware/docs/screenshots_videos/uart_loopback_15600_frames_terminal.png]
UART loopback: 15,600 frames at 2 Mbaud, no errors


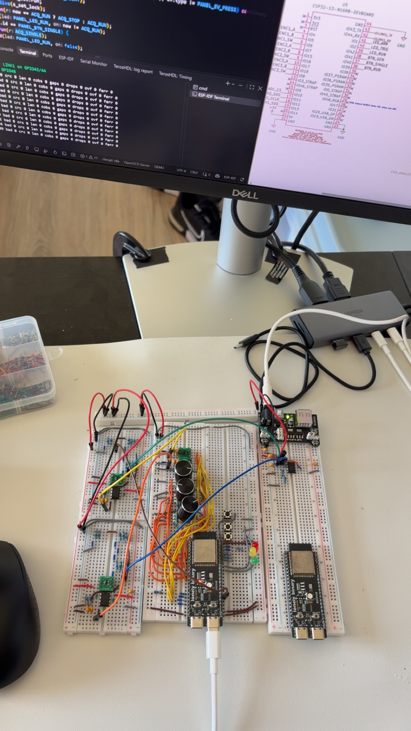
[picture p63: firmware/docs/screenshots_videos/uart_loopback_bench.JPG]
Loopback on the bench, LINK1 pins on the schematic


Board 1 to board 2. The two boards are now wired to each other: each
TX through a 220R to the other's RX, grounds joined. Board 1 sends every
decimated frame (a 64-byte header plus min and max for both channels,
6.5 KB) and every panel event, board 2 sends pings and settings back,
and board 1 answers settings with its run state and actual sample rate.
One shared header defines every message so all three boards agree.

About 31.8 frames/s arrive, which is what 2 Mbaud allows for 6.5 KB
frames, with zero CRC, length or dropped-byte errors. Every encoder
turn, press and release shows up on board 2. RUN reports STOP, SINGLE
reports SINGLE then STOP after one frame, and a settings change from
board 2 comes back confirmed. Ping round trip is about 40 ms because a
ping waits behind a frame that takes 33 ms to send.

The COBS and framing errors in the screenshot are from unplugging. With
one board unpowered, the other kept driving its RX pin, which back-powers
the dead chip through its pin, it then came up with a stuck USB port
until reset. The counts stay flat while both run, so no new errors. The
220R resistors are there to keep that current small. Rule for the bench:
power both boards together, or reset the one plugged in last.

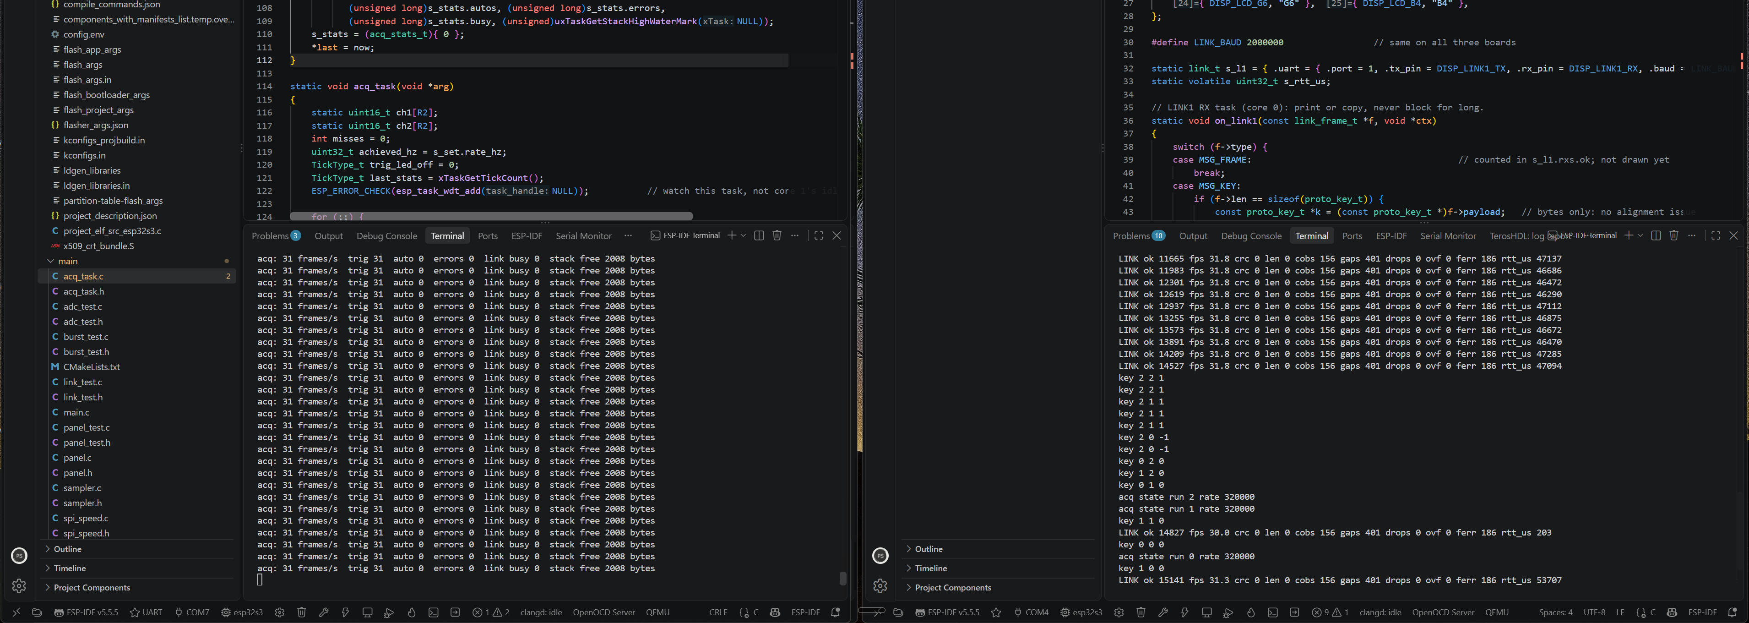
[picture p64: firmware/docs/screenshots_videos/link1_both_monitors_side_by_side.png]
Both monitors: frames, keys and state messages


Board 1 and board 2 on the bench, crossed LINK1

[Video: LEDs and keys with the link running](docs/screenshots_videos/link1_leds_keys_demo.MP4)

Display prep. Soldered header pins onto the four display boards: the
Adafruit 40-pin TFT breakout for the panel ribbon, the 6-pin FPC
adapter for the touch ribbon, the XL6009 boost for the backlight and
the 5 V input. Beeped every pad against its neighbour for shorts and
against the pin it should reach. All clean.

Mapped the breakout against Adafruit's schematic before wiring anything.
The silkscreen matches this panel's RGB, clock, sync, DE and DISP pins,
but three things differ. The breakout ties ribbon pins 3 and 36 to
ground and leaves 35 open, on this panel those are the SPI chip select,
data and clock, so the panel runs its default RGB mode and the CS/SPI
tie-offs on my schematic are left out. The LA pad has a 24 V clamp
diode across the LED string for the breakout's own driver, this
backlight needs 25.6 V, so the diode comes off before the XL6009 drives
it. And 5VIN powers the breakout's boost chip, so it stays unconnected.

First fit the ribbon went in flipped and every pin came out mirrored
(pin 1 on YU). Caught it with the meter before powering anything.

Parts laid out before soldering

Breakouts soldered, continuity and short check

Backlight, alone. Set the XL6009 with nothing on its output first: it
turns down to about 5 V (a boost can't go below its input) and up past
22 V, so the module regulates. Parked it at 20 V, below where the LED
string turns on. Then wired OUT+ through a 100R to LA and LK to ground,
and crept the trimpot up with the meter across the resistor.

Almost no current at first, then it came up fast once the string
turned on, the knee 8 LEDs in series predict. At 25.5 V out it was
3.0 V across the 100R (30 mA). Stopped at 4.0 V across the 100R:
40 mA, two thirds of the rated 60 mA and well under the 75 mA maximum.
The booster reads 27 V, so the string drops about 23 V. Used 100R
instead of the schematic's 75R (the resistor kit has no 75R), it
dissipates 0.16 W at 40 mA, inside its rating.

The breakout's own 24 V clamp sits across the string. At 23 V it stays
below its threshold, and after a minute everything on the breakout was
cool, so it stayed on the board. Nothing else of the panel is connected
yet, so the glow is plain white.

Backlight lit at 40 mA from the XL6009

Colour bars, first attempt. Before wiring, reordered board 2's LCD pins
so the left header runs in the breakout's pad order: reds, then all five
blues, then all six greens, then the pixel clock. The LCD peripheral
reaches its pins through the GPIO matrix, so any free pin can carry any
bit, same 27 GPIOs, only the labels and the pin header changed. Wired
the 16 data lines, clock, HSYNC, VSYNC and DE, tied the unused low bits
(R0 to R2, G0, G1, B0 to B2) to ground and ON/OFF high through 10k. The
breakout already grounds the panel's SPI chip select and data pins, so
the CS/SPI tie-offs on my schematic have nowhere to go and are left
out. Touch ribbon wired too, with 2k pull-ups on SCL and SDA for margin.

The firmware side is up: the panel driver starts at 800 x 480, 16 MHz
pixel clock, 32.8 Hz refresh, and the test cycles bars, bits and border.
The panel stays plain white, which is what it shows with backlight but
no working logic. Next: DC-check the 3.3V, GND, ON/OFF, CLK (should
average about half the rail), HSYNC, VSYNC and DE pads, and reseat the
ribbon.

First bring-up: test running, panel still white

What it should show, drawn from the test code: colour bars, then one band
per data wire (dim to bright blue, green, red), then a 1-pixel border.

Expected test patterns

## 2026-09-29

Colour bars, fixed. The white screen was power, not signals. The panel's
3.3 V read 2.3 V off the breadboard supply, below its 2.7 V minimum, and
the supply's parts ran hot. Moving the panel to board 2's own 3.3 V (as
the schematic has it) dragged that rail to 2.2 V too, so something on
the breakout was loading it.

Adafruit's schematic explains it. The breakout's 3.3V pad is the output
of its own small regulator, whose input is 5VIN. Feeding 3.3 V into that
pad leaks back through the regulator onto 5VIN, and 5VIN also powers
the breakout's backlight boost chip, whose enable pin (PWM) is pulled up
to 5VIN. So the boost chip switched itself on and pulled hard on my
3.3 V rail. Tied PWM to ground to hold it in shutdown, left 5VIN
unconnected, and the rail holds at 3.3 V.

Now the panel's logic, touch, pull-ups and ON/OFF all run from board 2's
3.3 V, so the panel switches on and off with the board, and the backlight
stays on its own 5 V through the XL6009. Colour bars come up, and the
test cycles through the bit bands and the border.

Colour bars on the panel

RGB bus wiring into the breakout

[Video: test patterns cycling](docs/screenshots_videos/lcd_test_patterns_running.MP4)

Touch controller answers. A throwaway I2C scan on board 2 found the
GT911 at 0x14 (it picks 0x14 or 0x5D from the INT level at reset, which
the scan left floating), and a short poll read its product ID back as
"911" and printed X/Y as I dragged a finger around. Test code reverted,
the real driver comes later and will drive INT to pin the address.

Generator next. The resistors arrived, so the R-2R ladder goes on board
3 tonight. Changed the ladder to use one value only: every 2R leg is a
single 10k and every R is two 10k in parallel (5k), 23 parts. The ratio
is what sets linearity, and same-value parts hold 2:1 by construction,
parallel pairs also sit in one pair of breadboard rows where series
pairs need a middle row each. Tolerance math for 1% parts gives about
0.5 LSB typical at the mid-scale carry, so I'll meter the 10ks and put
the closest ones at the D7/D6 end. Ladder output drops from 10k to 5k,
which moves the Sallen-Key filter from 23 kHz (Q 0.73) to 33 kHz
(Q 0.69) with R38 left at 10k. Still flat, just a slightly higher
corner.

Bench set up for the ladder

## 2026-09-30

Ladder bit weights. Each bit set alone, measured at the ladder output
(the R38 row) against board 3's 3V3 pin, 3.288 V. Expected is
3.288 x code / 256. Meter zero offset of 0.7 mV subtracted.

| Code | Bit | Expected | Measured | Error |
|---|---|---|---|---|
| 0 | none | 0 | 0.7 mV | meter offset |
| 1 | D0 | 12.8 mV | 12.7 mV | -1% |
| 2 | D1 | 25.7 mV | 25.7 mV | 0% |
| 4 | D2 | 51.4 mV | 51.5 mV | +0.2% |
| 8 | D3 | 102.8 mV | 102.9 mV | +0.1% |
| 16 | D4 | 205.5 mV | 205.2 mV | -0.1% |
| 32 | D5 | 411.0 mV | 409.7 mV | -0.3% |
| 64 | D6 | 822.0 mV | 817.3 mV | -0.6% |
| 128 | D7 | 1.644 V | 1.651 V | +0.4% |
| 255 | all | 3.275 V | 3.271 V | -0.1% |

Every bit within 1% on 1% parts, with the all-10k ladder (2R single,
R as parallel pairs). The MSB is 0.4% high, about half an LSB at the
127 to 128 carry, so the output stays monotonic.

Two traps on the way. First reading at code 255 was 2.2 V, which was
the D0 node, not the output: with all bits high, the node next to the
terminator sits at 2/3 of the rail, and a quick nodal solve matched it
to the millivolt. Then the single bits read almost zero while 128 and
255 read the full rail, because I was probing the top of R37, which is
GPIO11 itself. The output is the bottom of R37, the row R38 starts in.

Also found board 3's 3V3 at 2.9 V on USB. Not the board: the USB hub
was also charging my phone and its 5 V sagged. Unplugged the phone and
the rail came back to 3.288 V.

Ladder built beside the generator sheet

Bit test running, code 0 at the ladder output

Ladder staircase. Swapped the bit test for the ramp: codes 0 to 255,
20 us each, on repeat. On the scope at the ladder output it's a clean
sawtooth, 0 to 3.28 V by cursor, repeating every 5.44 ms. That's a bit
longer than the ideal 5.12 ms (256 x 20 us) because each code also pays
for the loop and the store, and every 64th ramp yields a tick to the
idle task, so about 21 us per code in practice. At 2 ms/div the 12.8 mV
steps are too fine to see, which is expected, the bit-weight table
above already puts the 127 to 128 step within half an LSB.

Staircase on the scope, cursors on one ramp

[Video: staircase running](docs/screenshots_videos/gen_r2r_staircase_running.MP4)

Waveforms from a timer interrupt. A 32-bit phase accumulator adds a
tuning word every sample, and the top 8 bits pick the next code: from a
256-entry sine table, a compare for square, the index itself for saw,
folded for triangle. f_out = tw x 100 kHz / 2^32, so 1 kHz is
tw = 42,949,673 and the step is about 23 uHz. The math is pure C and
host-tested first: tuning word, 1234 Hz counted over 10 s to +-1 cycle,
10% duty, range limits, table landmarks. All seven host suites pass.

On the board it runs in a 100 kHz Timer Group 0 interrupt on core 1,
set up from the registers. The ISR acknowledges, re-arms, then does one
DDS step and one GPIO_OUT store. Everything it touches lives in IRAM or
RAM: the sine table isn't const (a const table lands in flash), and the
shape select is if/else, not a switch that GCC could turn into a jump
table in flash.

Checked at the ladder output: sine, square 50% and 10%, saw and
triangle at 1 kHz, sine at 100 Hz, 5, 10 and 20 kHz. At 10 kHz a sine
is only ten steps per cycle, which is the limit the filter has to work
with. ISR execution time on the timing pin not measured yet.

Sine, 1 kHz, unfiltered

Square, 1 kHz

Saw, 1 kHz

Triangle, 1 kHz

Seven host test suites passing, DDS added

LVGL on the panel. The display now draws through LVGL 9.3 and
esp_lvgl_port instead of filling the framebuffer by hand. Two PSRAM
framebuffers with tearing avoidance (LVGL draws one while the panel shows
the other), and 10-line bounce buffers in internal RAM so the LCD DMA
never waits on PSRAM. LVGL renders on core 1, the RGB refill interrupt
stays on core 0. First screen is plain: the default light theme, "Oscil"
centred, and LVGL's FPS/CPU monitor in the corner. Held still for a
minute with no drift or tearing.

Two snags. The build failed first: the manual pinned LVGL 9.2 but the
newest esp_lvgl_port 2.x uses a colour format added in 9.3, so the
manifest now allows LVGL 9.3. Then the grey text and the monitor box came
out purple. The bit-line test showed why: black was maroon, and the last
band (R7 alone) matched the background, so R7 was stuck high. The
jumpers on that side of board 2 had shifted two rows, putting R5 and
below on the wrong header pins, one of them 3V3. Moved them back and
black is black again.

LVGL hello screen

RGB bus wiring, panel flipped

[Video: LVGL hello screen running](docs/screenshots_videos/lvgl_hello_running.MP4)

Touch. The GT911 now runs through Espressif's esp_lcd_touch driver and
feeds LVGL as an input device. At reset the driver holds INT low, which
makes the chip answer at 0x5D instead of the 0x14 the earlier throwaway
scan found, the boot scan sees exactly one device at 0x5D and reads the
product ID back as "911". A red dot follows the finger and every press
prints its coordinates. X and Y come out in the right directions, no
mirroring or swap needed.

Touch coordinates in the monitor

[Video: dot following the finger](docs/screenshots_videos/touch_dot_following_finger.MP4)

Scope view, first try (not working yet). Board 2's links moved into their
own module, and a scope view draws the min/max frames from board 1 onto
an 800x400 plot: a graticule drawn once and copied each frame, one
vertical run per column from min to max, CH1 yellow and CH2 cyan, and
two frame slots between the link task and the renderer so a slow draw
drops old frames instead of tearing. Screen comes up with the plot and
the grid, but no trace.

The LINK line says why: about 1 frame/s gets through instead of the 30
board 1 sends, and the CRC, COBS and length counters climb fast. FIFO
overflows, ring drops and framing errors all stay at 0, so board 2 keeps
up and the baud matches, the bytes are arriving with bits flipped. Since
the board 1 to 2 test passed at 31.8 frames/s before the
display was running, this points at the wiring rather than the code:
the 16 MHz pixel clock and 16 data lines now switch next to the link
wires, and the grounds run through long breadboard jumpers.

Along the way the bench 5 V sagged to 4.1 V under load. The backlight
boost draws about 260 mA, and the breadboard module makes 5 V from 9 V
with a small linear regulator that has to burn 4 V x 0.3 A, about
1.2 W. Moved the XL6009 to its own bench supply at 5.0 V, the module
now only feeds the front end and holds 5 V.

Next: short ground between boards 1 and 2 beside the link wires, link
wires routed away from the display bundle, and 1 Mbaud as a fallback.

What it should look like:

Expected scope view (illustration)

What it does today:

Scope view, grid only, link corrupting frames

[Video: scope view first try](docs/screenshots_videos/scope_view_first_try.MOV)

## 2026-10-01

Scope view, live. Board 1's frames now draw on board 2's screen: the
1 kHz test square on CH1 over the graticule, the link at 31.8 frames/s
with zero errors. Getting there took a day of isolation tests, because
the failure only showed up with everything running.

The symptom: about 1 good message per second, CRC, length and COBS
errors climbing, a grid with no trace. Each piece was added back alone,
one flash per test: link only, then the panel, LVGL, touch, and the
scope view with no frames fed to it. All clean at 31.8/s. Connecting the
frame callback broke it again, and leaving the drawing task asleep while
still receiving and copying frames made it clean. So the trigger was the
drawing, not the wiring.

Drawing alone exposed the real counter: ovf, the UART's hardware RX FIFO
overflowing. Each frame the scope task copies a 640 KB background in
PSRAM and redraws the traces, about 34 ms of heavy memory traffic, and
the UART interrupt on core 0 couldn't always empty the 128-byte FIFO in
time. Four changes fixed it:

- UART interrupt raised to level 3 so it runs ahead of the display's.
- RX FIFO threshold from 64 to 32 bytes: more headroom before overflow.
- On overflow, reset the RX FIFO instead of only counting it. Before
  this, one overflow left the receiver broken for good, now it costs a
  frame and the decoder resyncs on the next delimiter.
- A 10 ms pause after each draw, so core 1's idle task runs (the task
  watchdog was firing) and PSRAM gets a gap. ovf stayed at 0 after this.

Then a crash on re-enabling the measurement labels: LVGL's built-in
printf doesn't do %f, lost its place in the argument list and read a
float as a string pointer (NULL). Formatting with the C library's
snprintf first fixed it.

Where it stands: stable, 8 frames/s on screen with the full canvas
redraw (target 25+), and the trace is live but not clean yet, with
gaps in the highs. The captured data from board 1 was a clean 50% square
when dumped earlier, so the next look is board 2's drawing path, along
with only redrawing what changed to get the frame rate up.

Before the fix, link errors climbing while frames draw:

LINK errors while drawing

After the fix, link clean at 31.8/s with the scope drawing:

LINK clean while drawing

First trace on screen, with the gaps in the highs:

First live trace

The scope view running on the bench, board 1's 1 kHz square on CH1:

Live scope view on the bench

Measurements. Board 1 now measures each channel from the full
1600-sample record, before decimation, and sends the results in the
frame header: min, max, peak to peak, average, true RMS (DC included),
frequency and duty. Board 2 only displays them. Average and RMS come
from one pass with double accumulators, frequency reuses the trigger:
every rising crossing of the midpoint (10% hysteresis) across the
record, first to last with the sub-sample fractions, over the achieved
sample rate. Duty is the share of samples above the midpoint. Host
tested first: DC, sine RMS, a 1 kHz sine within 0.1%, a 25% square.
Eight host suites pass.

On the 1 kHz test square, nominal calibration:

| Measurement | Oscil | Expected |
|---|---|---|
| Frequency | 996.0 Hz | 1000 Hz |
| Duty | 50.0% | 50% |
| Average | 1.749 V | midway between the levels |
| RMS | 2.431 V | high level / sqrt(2) |
| Min / max | -0.235 / 3.590 V | levels about -0.13 / 3.45 V, plus noise |
| Peak to peak | 3.825 V | max - min |

The level offsets are the nominal calibration, the real one comes later.
The link stays at 31.8 frames/s with zero errors and board 1 still
captures 31 frames/s with the measuring added.

Measurement panel on the 1 kHz square

Bench with measurements running

Host tests, measurements added

Link clean, board 1 measuring

[Video: measurements running](docs/screenshots_videos/measure_running.MP4)

## 2026-10-02

Controls. Board 2 now owns every user setting in one struct, and every
input goes through one function: the knobs and buttons on board 1 arrive
as key messages, the touch buttons call it directly, and both change the
same settings. Board 1 only reports turns and presses, it no longer
toggles RUN or SINGLE itself (a compile-time switch keeps that for
running board 1 alone), so a press can't toggle twice. Changes go out
only to the board that needs them: timebase and trigger to board 1,
V/div and channel on/off stay on the display. At startup board 2 pushes
its settings to board 1, so after a display reset both agree. Keys from
the link task reach the UI through a queue, so the link never waits on
the display lock.

Knob map: ENC1 timebase, ENC2 V/div of the selected channel (push swaps
channel), ENC3 trigger level (push flips the edge). Top bar: RUN/STOP,
SINGLE, CH1, CH2, TRIG, MEAS, PHOS, GEN, SAVE. The status bar shows
timebase, both channels' V/div, and the trigger source, edge, level and
mode.

Two problems on the way:

- Boot loop: the status bar was formatted with LVGL's own printf, which
  has no float support. The trigger voltage shifted the arguments and the
  last string pointer was garbage. Formatted with libc snprintf instead,
  the same fix as the measurement labels.
- In STOP the trace ignored V/div, because the canvas only redrew when a
  new frame arrived. A view change now redraws the last frame. Timebase
  and trigger still apply on the next capture: board 1 sends decimated
  columns, so a stopped trace can be rescaled vertically but not in time.

In STOP the link drops to the ping and state messages (0.9 messages/s)
and comes back to 31.8 frames/s with zero errors on RUN.

Stopped, status bar showing the settings

Link in STOP and RUN, board 1 still capturing on demand

[Video: knobs and touch driving the scope](docs/screenshots_videos/controls_knobs_and_touch.MOV)

Generator screen. A second LVGL screen for the generator: shape buttons,
frequency (tap for a numeric keypad), amplitude and offset sliders, a
duty slider shown only for square, output on/off, and a one-period
preview. Every widget calls the same action function as the knobs, and
that function refreshes the screen after every generator change, so
touch and knobs follow each other both ways without loops (LVGL setters
send no events). Amplitude and offset are the DDS's own lo/hi codes,
clamped so neither leaves 0..255. The preview is drawn by dds_next(), the
same code board 3 runs in its timer interrupt, so the picture can't
disagree with the output. Board 2 sends the settings on LINK2 every
500 ms, board 3 starts following once its receiver is in.

Generator screen, 250 Hz sine with the preview

LINK2. Board 3 now listens. LINK2 is one-way, so board 3 can't
acknowledge anything, instead board 2 sends the whole generator state
right after every change and again every 500 ms, and board 3 applies
whatever arrives. A lost frame is corrected within half a second, and
receiving the same state twice changes nothing. Board 3 flashes its LED
white per frame, then green for output on or dim red for off, and logs
each change plus a status line every 5 s (frames received, time since
the last one, or a warning if the link goes quiet). Frames arrive about
every 500 ms with no gaps.

The generator screen also got easier to read: frequency is a button
that opens the keypad, each slider shows its value (Vpp, V, %), the
switch is labelled, and an output card at the bottom summarises the
setting ("1 kHz Sine, 0.00 to 3.30 V, output on"). All float text goes
through snprintf.

Three boards: generator screen, board 3 following

Board 3 log: frames every 500 ms, the applied setting

Settings and calibration. Board 2 now saves its settings (timebase,
V/div, trigger, channels, generator) to NVS two seconds after the last
change, with a version number and a CRC, and restores them at boot. A
burst of knob turns is one flash write, not dozens.

Board 1 has a two-point calibration per channel, stored in its own NVS
and sent to board 2 at boot. The procedure: input to GND (zero), then
input to the 3.3 V analog rail measured with a DMM (span), averaging
4096 samples each. The inputs are the top of the 750k divider resistors,
the same node the BNC centre goes to.

| Channel | Zero (codes) | Span (codes) | Gain | Offset |
|---|---|---|---|---|
| CH1 | 2067.2 | 3092.9 | 3.9442 | 1.6725 V |
| CH2 | 2074.0 | 3098.6 | 3.9481 | 1.6781 V |

Span source 3.273 V. Nominal was gain 4.0 and offset 1.65 V, about 1.4 %
and 25 mV off, which is what had the step 36 levels reading wrong. After
calibration the 1 kHz test square reads min -0.106 V, max 3.526 V,
avg 1.735 V, 996.0 Hz, 50.0 % duty (min/max include the trace noise).

It took four runs. The first ran with the sampler still active, so two
tasks drove the ADC bus at once. The second used a span value taken while
the analog rail was sagging. The third had CH2 reading the same code
(about 2763, the 2.2 V reference level) whatever the input: the jumper
wasn't in the R7 row, so the divider input was floating. The fourth was
clean, and the two channels agree within 0.1 %.

Spikes after rewiring. For a while both channels showed single samples
jumping to the edge of the screen. Every bad sample was off by exactly
2048 codes, the ADC's most significant bit, so it was a bit error on the
SPI read, not analog noise. Slowing SCLK from 26.67 to 20 MHz made it
worse (the sampler's timing is built around 26.67 MHz) and was reverted.
The spikes then stopped with the original code after the jumpers were
re-seated, so the cause was a marginal connection. If they come back:
press on the SCLK, CS and SDO jumpers while watching, and the CS setup
time (one clock now) is the first margin to add.

Calibration on the bench: DMM on the span source

Calibration results on the monitor

1 kHz square after calibration

Small display changes. Minor ticks on the scope's centre axes, five per
division, so a level can be read to a fifth of a division. A faint 4 x 4
grid in the generator preview, so amplitude and offset show where the
wave sits in the 0 to 3.3 V range. The generator output now always
starts off at power-up, whatever was saved, shape, frequency, amplitude
and offset are still restored.

Scope with minor ticks, calibrated 1 kHz square

Generator preview with its grid

Partition table. All three boards now use the same 16 MB layout:

| Partition | Offset | Size |
|---|---|---|
| nvs | 0x9000 | 24 KB |
| otadata | 0xF000 | 8 KB |
| phy_init | 0x11000 | 4 KB |
| ota_0 | 0x20000 | 4 MB |
| ota_1 | 0x420000 | 4 MB |
| storage (LittleFS) | 0x820000 | 7.9 MB |

Two app slots so an update can be written to the slot that isn't running
and rolled back if it fails, app rollback is on in the bootloader. NVS
kept its offset and size, so board 2's settings and board 1's
calibration survived. The images are far below a slot: board 1 about
241 KB, board 2 about 654 KB, board 3 about 213 KB.

The first build ignored the new settings: sdkconfig.defaults is only read
when no sdkconfig exists, and each board already had one. Set the custom
table and rollback in menuconfig on each board, and kept the lines in
sdkconfig.defaults so a fresh clone builds the same way.

All three boards building with the 16 MB table

## 2026-10-03

Board 2 joins Wi-Fi as a station. Everything is event-driven: the
driver reports start, disconnect and got-IP as events, and other tasks
wait on one event-group bit (online) instead of polling. A dropped
connection retries with exponential backoff, 1, 2, 4, 8, 16, 32 s up to
60 s, from a one-shot FreeRTOS timer, so a rebooting router isn't
hammered. SNTP starts once on the first IP so captures get real times.
Credentials are compiled in from a git-ignored secrets.h, provisioning on
the device is future work.

The ESP32-S3 radio is 2.4 GHz only and the home network is 5 GHz, so it
runs on a phone hotspot with its 2.4 GHz compatibility mode on. First
attempts showed the backoff working but never connecting, on the hotspot
it joined on channel 6, WPA2, RSSI -39 dBm, and got 172.20.10.6 by DHCP.
The scope and LINK1 kept running throughout: 31.8 frames/s, no errors.

Backoff while the network is unavailable

Connected to the hotspot

OTA. Board 2 now updates from SYS, using the display binary on the
latest GitHub Release. HTTPS checks the server certificate against
ESP-IDF's bundled roots, writes the other app slot, verifies the image
and sets it for the next boot. SYS shows the firmware version, Wi-Fi
state and RSSI, free and minimum heap, and the scope frame rate.

The first attempts reset while writing flash with the display running.
One watchdog reset stopped in the panic handler, later runs caught
illegal instruction and instruction-fetch errors. Pausing the scope
task, then holding the LVGL lock for the download, did not make it
reliable. The lock also held up UI callbacks from the link receiver,
so incoming bytes were dropped. An update with the LCD left unstarted
completed. That narrowed the problem to the display setup alongside
OTA, but did not identify the exact cause. The panic handler is now in
IRAM so failures during flash operations can be reported.

The update button now saves a one-time request in NVS and reboots.
Before starting the LCD, touch or LVGL, the next boot consumes the
request and starts an OTA task. It waits up to 30 s for Wi-Fi, downloads
with the screen disabled, then reboots. LINK1 keeps draining frames
without UI callbacks. A failed attempt returns to normal startup, the
request is already cleared, so another reset cannot start an update
loop.

Tested from 0.8.0 to 0.8.1, starting with the touchscreen button. The
download took about 26 s after entering update mode, the new image
booted from ota_1 at 0x420000, and the self-test confirmed it. The test
checks the LCD, touch and a recent frame from board 1, allowing up to
5 s for that frame. The screen returned and LINK1 stayed at about
31.8 frames/s with zero errors during the download and after reboot.

```text
ota: update requested, rebooting without LCD
ota: update mode: LCD, touch and UI disabled
ota: done, rebooting
App version: 0.8.1
ota: 0.8.1 is new: self-test
ota: new image confirmed
```

Update mode, certificate checks and the download starting

0.8.1 confirmed, scope running and LINK1 clean

[Video: touchscreen update from 0.8.0 to 0.8.1](docs/screenshots_videos/ota_update_0_8_0_to_0_8_1.MP4)

Accounts on board 2. Added the Supabase HTTPS client and account session
code. Requests use the bundled certificate roots and the publishable key,
user requests carry the access token. The refresh token, username and user
id are saved in NVS. The access token stays in RAM and is renewed when
needed, including after reboot.

Tested sign-in as `paul_test`. TLS validated, sign-in returned ESP_OK and
the token was 800 characters. After a reset, the test printed "session from
NVS: paul_test" and obtained a token again without another password login.
Forced sign-out for the negative test, then supplied a wrong password.
It returned "Wrong username or password" with ESP_FAIL and no valid token.

LINK1 stayed at 31.8 frames/s in the sign-in run. The reset run recorded
one length error, 44 gaps and 281726 dropped bytes at startup, those counters
stayed flat in the following logs and reception returned to 31.8 frames/s.
The cause of that startup disturbance is not established. The scope drew
at about 4.7 fps, around 203 ms per frame, slower than the earlier run.

Device sign-in succeeded

Session restored after reset

Wrong password rejected, no token issued

Account screen. SYS now opens a page with Sign in, Create account and
Forgot password modes, a text keyboard, account status, Sign out and Back.
Password fields are masked. Create account asks for a secret phrase, reset
asks for that phrase and a new password. Network requests are queued to a
worker task so the LVGL task does not wait on HTTPS.

The manual's SYS replacement called the old OTA function. Kept the working
NVS request and reboot updater, so adding Account does not restore the
update path that failed with the LCD running.

The first touchscreen sign-in validated the certificate, then failed with
"esp-aes: Failed to allocate memory" and a TLS read error. The hardware AES
path needs temporary DMA-capable buffers, its allocation failed. Disabled
hardware AES in menuconfig and saved the same setting in sdkconfig.defaults.
TLS now uses software AES, with certificate checking still enabled. Account
operations worked after this change. Exhaustion versus fragmentation of
the DMA heap was not measured.

Recorded the three account screens, button navigation, password reset and
sign-in with the new password. Captures are kept with the firmware evidence,
the Supabase setup and PC isolation test stay under software.

Account sign-in screen

Create account screen

Forgot password screen

[Video: account screen buttons](docs/screenshots_videos/account_screen_buttons.MP4)

[Video: account screen navigation](docs/screenshots_videos/account_screen_navigation.MP4)

[Video: forgot password test](docs/screenshots_videos/account_forgot_password_test.MP4)

[Video: password reset and sign-in with the new password](docs/screenshots_videos/account_reset_new_password_sign_in.MP4)

Cloud photos. SAVE now takes a screenshot of the scope screen into RAM
and uploads it directly to the signed-in user's private Supabase folder.
The earlier file uploader expected a locally saved .osc capture, replaced
that path with an LVGL snapshot and BMP upload. No photo is written to
LittleFS. NVS keeps a screenshot counter across normal reboots.

The RGB565 snapshot is streamed as a 24-bit BMP, one converted row at a
time. An 800 x 480 image is 1,152,054 bytes. Raised the screenshots bucket
limit from 64 KB to 2 MB and saved the new limit in software/schema.sql.
The bucket remains private, with the existing owner policies.

Snapshot capture briefly takes the LVGL lock. The upload and metadata row
run on a worker task, a second SAVE while it is active reports "Photo
upload busy". Closing the request frees the snapshot. Signed-out SAVE is
refused. HTTP header and body read failures now return an error instead
of reporting a successful request.

The display rebuild compiled and linked, and the binary passed its app
partition size check with 65% free. Device testing passed: signed-out
SAVE showed "Sign in to save photos", repeated presses during uploading
showed "Photo upload busy", and a completed upload showed "Photo saved
to your account". Recorded the SAVE sequence and the resulting image in
Supabase.

The Account screen photo list and viewer are next. They are not part of
this change. The planned viewer will fetch only a selected photo into
RAM and free it when closed.

SAVE refused while signed out

Repeated SAVE presses while uploading

Photo saved to the signed-in account

[Video: cloud SAVE, busy guard and the Supabase image](docs/screenshots_videos/cloud_photo_save_busy_supabase.MOV)

### Photo viewer and selected trace touch

Added My photos to the signed-in Account screen. The gallery lists 20
metadata rows per page, newest first, it does not download thumbnails.
Tapping a row fetches that photo with the user's access token. The BMP is
read a row at a time and converted into one RGB565 PSRAM buffer, at most
768 KB. Close frees it and returns to the list. Leaving while a request is
running cancels its result, so an old download cannot reopen a photo.
The bucket and owner policies are unchanged.

Kept the scope layout and changed the top buttons to a dark background,
with a yellow or cyan border around the selected channel. Holding near
that trace for 300 ms starts dragging. Vertical movement changes only
that channel's voltage offset, horizontal movement pans only its display.
It does not change the sample rate or acquisition trigger position. ENC1
press centres it again. ENC3 and TRIG use the selected channel as source.
The persisted settings structure has not changed, horizontal pan starts
at zero after reboot. SAVE is refused away from the scope screen.

The display compiled and linked. Seven host tests passed for BMP headers,
both row directions, padding, RGB565 colours and malformed input.

Photo viewer startup correction. The first device attempt reported
"Photo viewer unavailable" before opening the gallery. That message came
from queue or worker creation, before any Supabase request. The worker
asked for a 12 KB internal stack, moved it to PSRAM and made the queue and
task control blocks static so startup no longer needs that internal heap
allocation. Kept PSRAM XIP enabled because token renewal can write NVS.
Added startup heap diagnostics and a "worker ready" log.

## 2026-10-04

### Gallery review

Rechecked the PSRAM worker stack, static queue/task controls, token use,
private folder paths, image bounds and cleanup when leaving a request.
The nine host suites passed, including the seven BMP cases. Corrected an
offline pagination case: Next, Previous and Refresh now keep the current
page when no request can start. Made gallery JSON parsing strict and
added HTTP/stage logs for a failed list or photo download. Photo requests
use the same 2 KB HTTP buffers as the uploader.

The signed-out guard and RAM-only photo path remain in place. Trace pan
is limited to the selected channel, with bounded horizontal positions,
ENC1 resets both offsets and trigger controls use the selected source.
A saved STOP state can still boot to an empty grid because waveform data
is not persisted. RUN with AUTO is the first check in that situation.

### Photo viewer on the device

Opened a saved cloud photo in the device viewer. The new capture shows
"Photo 4" with the saved scope image, both channel traces, measurements
and the Close control. This confirms gallery startup and a selected photo
being displayed after the worker startup correction.

Saved cloud photo open on the device

### Touch failure during sign-in

The display rebooted after a GT911 I2C timeout. The backtrace reached
LVGL's fatal touch-read check, it did not show an Auth rejection.
Added a project-side adapter that releases touch on an error, logs the
failure and lets the next read retry. Reduced the touch bus to 100 kHz
for the breadboard harness. Downloaded components are unchanged.

Moved the account worker's 12 KB stack into PSRAM with the same XIP
requirement as the gallery. Queue and task creation are checked, failed
submissions clear Working and show an error. Added request start/finish
logs without passwords, phrases or tokens.

### Photo numbering after the board swap

The replacement display started at photo 1 while the account still held
photos from the old board. Before allocating a number, the uploader now
reads the account's highest shot_id and keeps the larger of that next
number and the local counter. Existing photos are never overwritten.

Storage errors now include the server response in the serial log.
Recognised duplicate-file responses retry with a fresh number, up to
three uploads per save, using the same RAM snapshot. Other errors stop
the save. No SQL or policy changes are needed.

## 2026-10-05

### CI

The display build on GitHub Actions had failed since Wi-Fi was added.
Five display sources include the git-ignored `secrets.h`, so a clean
checkout could not compile them. The workflow now copies
`secrets_example.h` to `secrets.h` for the display job only, so CI
builds with empty credentials and nothing real reaches GitHub. Moved
`actions/checkout` to v5 to clear the Node 20 deprecation warnings.

## 2026-10-06

### Version 0.9.0

The display had stayed at 0.8.1 since the OTA test, so everything added
after it, accounts, cloud photos, the gallery, trace dragging and the
touch and photo numbering fixes, still reported 0.8.1. Boards 1 and 3 had
no version set and showed a git describe string instead. All three
projects now set `PROJECT_VER` to 0.9.0, checked in each built image, and
the three images go out together as one release, `v0.9.0`. Board 2 takes
it over Wi-Fi, boards 1 and 3 are flashed over USB.

</details>

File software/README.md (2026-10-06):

# Software

Supabase setup for Oscil accounts and cloud photos. Device code lives in
[`firmware/`](../firmware/).

| File | Job |
|---|---|
| [`schema.sql`](schema.sql) | Tables, row-level security and the private screenshots bucket |
| [`index.ts`](index.ts) | Account function: username signup and secret-phrase password reset |
| [`tests/isolation_test.py`](tests/isolation_test.py) | Two-user isolation, password reset and lockout tests |

## Setup

The project is `oscil-dev`, in West US. Email sign-in is enabled and email
confirmation is off because device accounts use `<username>@oscil.local`.

Run `schema.sql` once in the Supabase SQL editor. Keep the same SQL here so
the setup can be recreated. The private screenshots bucket allows 2 MB
per photo, the device uploads BMP images without saving them locally.
Project URL and publishable key go in the
firmware's git-ignored `secrets.h`. The service-role key stays on the server.

Paste `index.ts` into the Supabase Edge Function editor and deploy it as
`account`. Turn Verify JWT off so signup and reset can be called before
sign-in. Supabase supplies the service-role key in the function environment.

## Progress

| What | Status |
|---|---|
| Project and email settings | Done |
| Tables, security policies and private bucket | SQL applied successfully |
| Account function | Signup, duplicate rejection, password reset and lockout passed |
| Isolation tests | All 17 checks passed |

## Tests

Run from the repo root in PowerShell, with Windows Python and `requests`.
Set `SUPABASE_URL` and `SUPABASE_ANON_KEY` in that terminal, then run:

```powershell
python software/tests/isolation_test.py
```

Use the Windows Python executable directly if `python` points to MSYS2.
The script creates two test users and prints their names for cleanup.
Remove the test storage objects before deleting their Auth users.

## Build log

<details>
<summary><b>Open the software build log</b>: setting up Supabase and proving one user can never reach another's data</summary>

## 2026-10-03

Created `oscil-dev` in Supabase, in West US. Email sign-in is enabled,
confirmation is off. The device uses local account addresses that cannot
receive mail.

Applied `schema.sql` in the SQL editor. Supabase returned "Success. No rows
returned." The script creates `profiles`, `recovery` and `screenshots`, enables
row-level security, and creates a private screenshots bucket with a 64 KiB
file limit. Profile and screenshot policies restrict access to the signed-in
owner. Recovery has no client policies and its client grants are revoked.

The SQL is saved in the repo. The successful query confirms setup,
account and isolation checks were run separately below.

Supabase schema created

Deployed the `account` Edge Function from `index.ts`, with Verify JWT off.
The source uses Supabase's server-side service-role key to create the Auth
user, profile and recovery hash. The secret phrase is normalised and hashed
with PBKDF2-SHA256, a random salt and 100,000 iterations.

Tested signup from PowerShell with `paul_test`. The first request returned
`ok: True`. Repeating it returned HTTP 409 Conflict, rejecting the duplicate
username. Password reset, lockout and cross-account isolation were checked
with the two-user test below.

Account signup and duplicate rejection

Ran `tests/isolation_test.py` against `oscil-dev`. All 17 checks passed.
Both users could sign up and sign in. A uploaded a file and added its row,
B could not list or download it, write into A's folder, or insert a row as A.
The signed-out request returned no screenshots, and the recovery hash read
was refused. A could still read its own row.

Password reset refused the wrong phrase and accepted the right phrase with
different case and spacing. The old password stopped working, the new one
worked, and five wrong phrases locked further resets.

The PC's `python` command first resolved to MSYS2. Used Windows Python 3.13,
installed `requests` there, and set the Supabase URL and publishable key in
the PowerShell environment. The final run returned `ALL PASS`.

Supabase isolation tests passed

Raised the screenshots bucket limit from 64 KiB to 2 MB for the device's
800 x 480 BMP photos (1,152,054 bytes each). The change is saved in
`schema.sql`, the bucket stays private with the same owner policies.

</details>

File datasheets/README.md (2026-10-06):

# Datasheets

The PDFs live here locally but aren't committed (see `.gitignore`).
Each link below was checked against the local copy: same document, same
revision, unless the notes say otherwise. Page numbers in the schematic
notes and build logs refer to these revisions.

| Part | Used for | Revision used | Link |
|---|---|---|---|
| ADS7883 | 12-bit 3 MSPS ADC, one per channel | SLAS594, July 2008 | [TI product page](https://www.ti.com/product/ADS7883) · [PDF](https://www.ti.com/lit/ds/symlink/ads7883.pdf) |
| MCP6292 | Dual op-amp: VREF buffer, AFE buffers, generator | DS20001812G | [Microchip product page](https://www.microchip.com/en-us/product/MCP6292) · [PDF](https://ww1.microchip.com/downloads/aemDocuments/documents/MSLD/ProductDocuments/DataSheets/MCP6291-Family-Data-Sheet-DS20001812G.pdf) |
| MCP1700-3302E | 3.3 V LDO for the analog rail (+3V3_A) | DS20001826F | [Microchip product page](https://www.microchip.com/en-us/product/MCP1700) · [PDF](https://ww1.microchip.com/downloads/aemDocuments/documents/APID/ProductDocuments/DataSheets/MCP1700-Data-Sheet-20001826F.pdf) |
| BAV99 (SMC Diode Solutions) | Input clamp diodes | N0595 Rev. B | [SMC product page](https://www.smc-diodes.com/Products/Discrete/Diodes/BAV99.html) · [PDF, Rev. B](https://www.smc-diodes.com/propdf/BAV99%20N0595%20REV.B.pdf) |
| ESP32-S3 | MCU on all three boards | Datasheet v2.2 | [Espressif PDF](https://www.espressif.com/sites/default/files/documentation/esp32-s3_datasheet_en.pdf) |
| ESP32-S3 TRM | Register-level reference (GPIO, IO MUX, SPI, GDMA) | TRM v1.8 | [Espressif PDF](https://www.espressif.com/sites/default/files/documentation/esp32-s3_technical_reference_manual_en.pdf) |
| ESP32-S3-WROOM-1 (N16R8) | Module on the dev boards | Datasheet v1.8 | [Espressif PDF](https://www.espressif.com/sites/default/files/documentation/esp32-s3-wroom-1_wroom-1u_datasheet_en.pdf) |
| ESP32-S3-DevKitC-1 | Reference for the dev board header layout | esp-dev-kits docs | [Espressif docs](https://docs.espressif.com/projects/esp-dev-kits/en/latest/esp32s3/esp32-s3-devkitc-1/index.html) |
| WS2812B (Worldsemi) | Onboard status LED on GPIO48 | "Datasheet and Specifications" edition | [PDF (SparkFun mirror)](https://cdn.sparkfun.com/assets/e/6/1/f/4/WS2812B-LED-datasheet.pdf) |
| AFY800480B0-7.0N12NTM-C | 7" 800x480 RGB panel | Rev. E | [Orient Display PDF](https://www.orientdisplay.com/pdf/AFY800480B0-7.0N12NTM-C.pdf) · [DigiKey](https://www.digikey.com/en/products/detail/orient-display/AFY800480B0-7-0N12NTM-C/12089250) |
| GT911 datasheet | Touch controller on the panel | Rev. 09, March 2015 | [PDF (ElectroDragon mirror)](https://w2.electrodragon.com/Chip-dat/goodix-dat/GT911-dat/GT911-DS.pdf) |
| GT911 programming guide | Touch controller registers | Programming guide | [Orient Display PDF](https://www.orientdisplay.com/pdf/GT911.pdf) |

Notes:

- The dev boards are Lonely Binary ESP32-S3 N16R8 boards. The DevKitC-1 page
  is only a reference, header pin numbers in `hardware/docs/pin-map.md` are
  for the Lonely Binary board.
- BAV99: SMC has since released Rev. D. The design was checked against Rev. B.
- WS2812B and GT911: neither Worldsemi nor Goodix hosts a stable public link,
  so these point to well-known mirrors of the same documents.
- The EC11 encoders came with the seller's spec sheet only.

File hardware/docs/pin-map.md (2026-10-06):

# Pin map

Rev A, matches the schematic. Header pin numbers are for the Lonely Binary
ESP32-S3 N16R8 dev board.

## Board 1, acquisition

| Signal | GPIO | Header pin | Note |
|---|---|---|---|
| ADC_SCLK | 12 | 18 | SPI2 IO_MUX (FSPICLK), to both ADCs |
| ADC_CS | 10 | 16 | SPI2 IO_MUX (FSPICS0), to both ADCs, 10k pull-up |
| CH1_SDO | 13 | 19 | SPI2 IO_MUX (FSPIQ) |
| CH2_SDO | 11 | 17 | SPI2 IO_MUX (FSPID), dual-line read |
| ENC1_A / B / SW | 4 / 5 / 6 | 4 / 5 / 6 | |
| ENC2_A / B / SW | 7 / 15 / 16 | 7 / 8 / 9 | |
| ENC3_A / B / SW | 17 / 18 / 8 | 10 / 11 / 12 | |
| BTN_RUN / SINGLE / GEN | 39 / 40 / 41 | 36 / 37 / 38 | |
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

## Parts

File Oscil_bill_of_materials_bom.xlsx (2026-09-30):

Oscil — Bill of Materials
Two-channel digital storage oscilloscope · ESP32-S3 · prototype stage |  |  |  | Green = already owned
Paul Simbulan · Rev 0.4 · 30-Sep-2026 |  |  |  | Amber = gap, not yet sourced
# | Qty | Part | Description | Package | Unit $ | Ext $ | Source | Notes | Link
ANALOG FRONT END
1 | 4 | ADS7883SBDBVR | ADC, 12-bit 3 MSPS SAR, SPI | SOT-23-6 | $5.53 |  | DigiKey | Reference = supply rail | https://www.digikey.com/en/products/detail/texas-instruments/ADS7883SBDBVR/2047152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
2 | 4 | MCP6292-E/P | Op-amp, dual, 10 MHz, rail-to-rail | 8-PDIP | $1.27 |  | DigiKey | Ref buffer, AFE ch1, AFE ch2, generator: all 4 used | https://www.digikey.com/en/products/detail/microchip-technology/MCP6292-E-P/574102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
3 | 10 | BAV99 | Diode array, 75 V | SOT-23-3 | $0.13 |  | DigiKey | Input clamp to rails | https://www.digikey.com/en/products/detail/smc-diode-solutions/BAV99/6022507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
4 | 12 | Cylewet CYT1018 | Trimmer capacitors, 5-60 pF | THT | $0.57 |  | Amazon | Attenuator compensation | https://a.co/d/0cBGTOYl
5 | 5 | Superbat BNC | BNC female panel mount, solder | Panel | $2.20 |  | Amazon | CH1, CH2, GEN out, 2 spare | https://a.co/d/0bSwA5N5
6 | 20 | Cermant SOT23-6 adapter | SMD to DIP breakout | PCB | $0.42 |  | Amazon | For ADS7883 and BAV99 | https://a.co/d/09HmNMVi
7 | 1000 | LuminologyPro 1000-pc kit | Resistors 1/4 W 1% metal film, 25 values x 40, 1R-1M | THT | $0.01 |  | Amazon | No 75R/51R/150R/750k/249k in kit: ladder is all 10k (2R = 10k, R = 2x10k in parallel = 5k, match by meter), 75R = 100R||330R (76.7R), 51R = 47R+4.7R, 150R = 100R+47R, 750k = 680k+68k, 249k = 220k+33k. 10k budget: ladder 23 + tie-offs 4 = 27 of 40 | https://www.amazon.com/dp/B0F4P352BB
8 | 300 | EEEEE 30-value MLCC kit | Ceramic caps 10 pF-10 uF, 10 each, 50 V | THT | $0.03 |  | Amazon | Rev A: 470p, 1n, 2.2n, 10n, 1u from here. Dielectric unstated, DMM-verify. C0G for Rev B | https://a.co/d/0dSCox0r
POWER
9 | 3 | MCP1700-3302E/TO | LDO, 3.3 V, 250 mA | TO-92 | $0.50 |  | DigiKey | Analog rail (+3V3_A) only, 2 spare | https://www.digikey.com/en/products/detail/microchip-technology/MCP1700-3302E-TO/652680
10 | 5 | HiLetgo XL6009 | Boost module, 3-32 V to 5-35 V | Module | $1.90 |  | Amazon | Backlight 25.6 V @ 60 mA | https://a.co/d/02AsqIvb
11 | 1 | Caps 100 nF / 10 uF / 100 uF | Decoupling and bulk | THT | $0.00 |  | On hand
PROCESSING
12 | 3 | ESP32-S3-WROOM-1-N16R8 | MCU dev board | Module | $0.00 |  | On hand | #1 acquisition, #2 display, #3 generator | https://a.co/d/0bcMUA3H
DISPLAY AND TOUCH
13 | 1 | AFY800480B0-7.0N12NTM-C | 7" 800x480 RGB TFT + GT911 touch | Panel | $29.67 |  | DigiKey MP | EOL — sub: Newhaven NHD-7.0-800480EF | https://www.digikey.com/en/products/detail/orient-display/AFY800480B0-7-0N12NTM-C/12089250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
14 | 1 | Adafruit 1932 | 40-pin TFT FPC breakout | Module | $9.95 |  | DigiKey | Connector only — backlight drv unused | https://www.digikey.com/en/products/detail/adafruit-industries-llc/1932/5761222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
15 | 4 | MTCELL FPC 6-pin | FFC to DIP, dual 1.0/0.5 mm | PCB | $1.75 |  | Amazon | GT911 touch tail | https://a.co/d/07UskTTP
16 | 1 | ST7789 240x320 SPI TFT | Interim display, Phase 1 | Module | $0.00 |  | On hand | Render loop target before 7" arrives
USER INTERFACE
17 | 6 | WWZMDiB EC11 | Rotary encoder + knob cap | THT | $1.48 |  | Amazon | s/div, V/div, trigger level | https://a.co/d/0f5mQg6T
18 | 1 | KY-040 encoder | Rotary encoder | Module | $0.00 |  | On hand | Spare / 4th
19 | 1 | Tactile buttons, LEDs | RUN, SINGLE, GEN buttons · RUN, TRIG, ARM LEDs | THT | $0.00 |  | On hand
INTERCONNECT
20 | 1 | PRPC040SAAN-RC | Header, male, 40-pos, 2.54 mm | THT | $1.23 |  | DigiKey | Breakaway | https://www.digikey.com/en/products/detail/sullins-connector-solutions/PRPC040SAAN-RC/2775214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
21 | 560 | Dorhea jumper wire kit | Jumper wires, 14 values | - | $0.01 |  | Amazon | Breadboard interconnect | https://a.co/d/04z6zcu7
22 | 2 | Breadboard, 830 tie point | Prototype substrate | - | $0.00 |  | On hand
23 | 8 | HUAREW breadboard kit | Breadboards 2x 830 + 2x 400, 120 jumpers (per kit, 2 kits) | - | $2.50 |  | Amazon | Two kits: generator ladder and display need the extra space | https://a.co/d/0bRym9Uv
24 | 1 | Perfboard w/ ground plane | For RGB bus and 32 MHz SPI | - | $10.00 |  | NOT BOUGHT | Needed when breadboard fails
TEST AND VALIDATION
25 | 1 | FNIRSI 2C53T | Oscilloscope + Function Generator | - | $0.00 |  | On hand | VALIDATION GROUND TRUTH | https://a.co/d/01g446Bb
26 | 1 | FX2LP + PulseView | Logic analyzer | - | $0.00 |  | On hand | SPI bring-up, trigger latency | https://a.co/d/01g446Bb
27 | 0 | MCP4725 DAC breakout | 12-bit I2C DAC | Module | $8.00 |  | CANCELLED | Replaced by R-2R ladder on board 3
 |  |  | Parts purchased
 |  |  | Shipping, tariff and tax (all four orders) |  |  | $50.47
 |  |  | LANDED COST TO DATE
 |  |  | Outstanding gaps (amber rows)
 |  |  | Equipment on hand (green rows) |  |  | $0.00
Notes
1. Amazon unit prices are pack price / pack quantity, so Ext $ reconciles to the order totals.
2. Orders: DigiKey Inv 132648539 ($70.54) · DigiKey Marketplace Inv 132648493 ($52.56) · Amazon 111-6299766 ($61.16) · Amazon 112-0437042 ($7.67). Grand total $191.93. Later: Amazon EEEEE cap kit $9.99, HUAREW breadboard kit $9.99. 28-Sep: LuminologyPro resistor kit $6.39, second HUAREW breadboard kit $9.99.
3. Excluded: 2x CAN transceiver breakout (separate lab work, $7.90) and solder flux (consumable, $3.99).
4. Adafruit 1932's onboard backlight driver is rated 24 V / 7-LED strings. The panel is 8 LEDs at 25.6 V and will not light from it — the board is used for its FPC connector only, with the XL6009 driving LEDA/LEDK through a 75 ohm series resistor.
5. Display is end-of-life. Production substitute: Newhaven NHD-7.0-800480EF-ATXL#-CTP.
6. Filter caps are C0G by design (X7R shifts the corner with temperature and bias). Rev A uses the EEEEE kit with values DMM-verified; C0G returns for Rev B.

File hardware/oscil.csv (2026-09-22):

Reference | Qty | Value | DNP | Exclude from BOM | Exclude from Board | Exclude from Simulation | Exclude from Position Files | Footprint | Datasheet
C1,C2,C16,C17 | 4 | 1uF |  |  |  |  | ${EXCLUDE_FROM_POS_FILES}
C3,C4,C21 | 3 | 100nF |  |  |  |  | ${EXCLUDE_FROM_POS_FILES}
C5,C6,C10,C11 | 4 | 5-60pF |  |  |  |  | ${EXCLUDE_FROM_POS_FILES}
C7,C12 | 2 | 100nF |  |  |  |  | ${EXCLUDE_FROM_POS_FILES} | Package_SO:SOIC-8_3.9x4.9mm_P1.27mm
C8,C9,C13,C14 | 4 | 2.2nF C0G |  |  |  |  | ${EXCLUDE_FROM_POS_FILES} | Package_SO:SOIC-8_3.9x4.9mm_P1.27mm
C15,C18 | 2 | 10nF |  |  |  |  | ${EXCLUDE_FROM_POS_FILES}
C19 | 1 | 470pF C0G |  |  |  |  | ${EXCLUDE_FROM_POS_FILES}
C20 | 1 | 1nF C0G |  |  |  |  | ${EXCLUDE_FROM_POS_FILES}
D1,D2 | 2 | BAV99 |  |  |  |  | ${EXCLUDE_FROM_POS_FILES} | Package_TO_SOT_SMD:SOT-23 | https://assets.nexperia.com/documents/data-sheet/BAV99_SER.pdf
D3,D4,D5 | 3 | LED |  |  |  |  | ${EXCLUDE_FROM_POS_FILES}
J1 | 1 | USB_5V_IN |  |  |  |  | ${EXCLUDE_FROM_POS_FILES} | Connector_RJ:RJ45_Abracon_ARJP11A-MA_Horizontal
J2 | 1 | BNC_CH1 |  |  |  |  | ${EXCLUDE_FROM_POS_FILES}
J3 | 1 | BNC_CH2 |  |  |  |  | ${EXCLUDE_FROM_POS_FILES}
J4 | 1 | LINK1 |  |  |  |  | ${EXCLUDE_FROM_POS_FILES}
J5 | 1 | LCD_AFY800480_40P |  |  |  |  | ${EXCLUDE_FROM_POS_FILES} | Package_LCC:PLCC-84_29.3x29.3mm_P1.27mm | https://orientdisplay.com/pdf/AFY800480B0-7.0N12NTM-C.pdf
J6 | 1 | GT911_TOUCH_6P |  |  |  |  | ${EXCLUDE_FROM_POS_FILES} |  | https://orientdisplay.com/pdf/AFY800480B0-7.0N12NTM-C.pdf
J7 | 1 | XL6009_IN |  |  |  |  | ${EXCLUDE_FROM_POS_FILES} | Package_LCC:PLCC-44_16.6x16.6mm_P1.27mm
J8 | 1 | XL6009_OUT |  |  |  |  | ${EXCLUDE_FROM_POS_FILES} | Package_LCC:PLCC-44_16.6x16.6mm_P1.27mm
J9 | 1 | LINK1 |  |  |  |  | ${EXCLUDE_FROM_POS_FILES} | Package_LCC:PLCC-44_16.6x16.6mm_P1.27mm
J10,J12 | 2 | LINK2 |  |  |  |  | ${EXCLUDE_FROM_POS_FILES} | Package_LCC:PLCC-44_16.6x16.6mm_P1.27mm
J11 | 1 | BNC_GEN |  |  |  |  | ${EXCLUDE_FROM_POS_FILES}
R1 | 1 | 0R |  |  |  |  | ${EXCLUDE_FROM_POS_FILES} | Package_TO_SOT_THT:TO-92_Inline
R2,R10,R11,R15,R16,R17,R18,R24,R26,R28,R30,R32,R34,R36,R38 | 15 | 10k |  |  |  |  | ${EXCLUDE_FROM_POS_FILES}
R3,R22,R23,R25,R27,R29,R31,R33,R35,R37 | 10 | 20k |  |  |  |  | ${EXCLUDE_FROM_POS_FILES}
R4,R7 | 2 | 750k |  |  |  |  | ${EXCLUDE_FROM_POS_FILES}
R5,R8 | 2 | 250k |  |  |  |  | ${EXCLUDE_FROM_POS_FILES}
R6,R9 | 2 | 150R |  |  |  |  | ${EXCLUDE_FROM_POS_FILES}
R12,R13,R14 | 3 | 330R |  |  |  |  | ${EXCLUDE_FROM_POS_FILES}
R19,R20 | 2 | 4.7k |  |  |  |  | ${EXCLUDE_FROM_POS_FILES}
R21 | 1 | 75R |  |  |  |  | ${EXCLUDE_FROM_POS_FILES}
R39 | 1 | 51R |  |  |  |  | ${EXCLUDE_FROM_POS_FILES}
SW1,SW2,SW3 | 3 | EC11 |  |  |  |  | ${EXCLUDE_FROM_POS_FILES}
SW4,SW5,SW6 | 3 | SW_Push |  |  |  |  | ${EXCLUDE_FROM_POS_FILES} | Button_Switch_THT:SW_NKK_GW12LJP
U1 | 1 | MCP1700-3302E/T0 |  |  |  |  | ${EXCLUDE_FROM_POS_FILES} | Package_TO_SOT_THT:TO-92_Inline | https://ww1.microchip.com/downloads/aemDocuments/documents/APID/ProductDocuments/DataSheets/MCP1700-Data-Sheet-20001826F.pdf
U2,U3,U4,U10 | 4 | MCP6292 |  |  |  |  | ${EXCLUDE_FROM_POS_FILES} | Package_TO_SOT_SMD:SOT-353_SC-70-5
U5 | 1 | ESP32-S3-N16R8-DEVBOARD |  |  |  |  | ${EXCLUDE_FROM_POS_FILES} |  | https://lonelybinary.com/en-us/collections/boards/products/3-pack-esp32-s3-n16r8-dev-board-3-terminal-bases
U6,U7 | 2 | ADS7883 |  |  |  |  | ${EXCLUDE_FROM_POS_FILES} | Package_TO_SOT_SMD:SOT-23-6 | https://www.ti.com/lit/ds/symlink/ads7883.pdf
U8 | 1 | ESP32-S3-N16R8-DEVBOARD |  |  |  |  | ${EXCLUDE_FROM_POS_FILES} | RF_Module:ESP32-S2-MINI-1 | https://lonelybinary.com/en-us/collections/boards/products/3-pack-esp32-s3-n16r8-dev-board-3-terminal-bases
U9 | 1 | ESP32-S3-N16R8-DEVBOARD |  |  |  |  | ${EXCLUDE_FROM_POS_FILES} | RF_Module:ESP32-C3-WROOM-02 | https://lonelybinary.com/en-us/collections/boards/products/3-pack-esp32-s3-n16r8-dev-board-3-terminal-bases

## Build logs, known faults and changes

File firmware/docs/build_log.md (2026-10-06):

# Firmware build log

## 2026-09-21

Started firmware. Three ESP-IDF projects, one per board, plus a shared
folder so pin numbers and the link protocol only exist once.

## 2026-09-22

sdkconfig.defaults in each: 16MB flash, octal PSRAM, 1000 Hz tick,
console on USB Serial/JTAG. The 2MB and 100 Hz defaults both bit me
in earlier lab work, so each build gets checked against sdkconfig.

Pin numbers from pin-map.md are in a header per board. Firmware
never uses a raw GPIO number.

AFE scaling in shared. The divider bottom sits on 2.2 V instead of
ground, so 0 V at the BNC reads 1.65 V at the ADC. Vbnc = 4 x (Vadc - 1.65).

First build couldn't find oscil_pins_acq.h. An include path would've
found the header but not compiled the .c, so shared is a real component
now. Also caught display and gen still named project(acq).

Host tests with Unity run the real oscil_afe.c on my PC. 4/4 pass.
They check the math, not the hardware. CI runs them on every push
that touches firmware, and the badge on the README shows the result.

Status LED heartbeat on all three boards. GPIO goes through registers
in oscil_gpio.h, no driver. The WS2812 is bit-banged off the CPU cycle
counter: 24 bits GRB, 0.4 or 0.85 us high in a 1.25 us bit, interrupts
masked for the ~30 us frame. Blink task pinned to core 0.
Acq green, display red, gen blue.

First build died on -Werror=misleading-indentation. A `while (...);`
wait loop with the next line one space off. Empty loops get `{ }` now.
First flash wasn't one either: only the monitor ran, and board 1 was
still booting an old lab.

Before: three projects, one command each

After: all three boot, heartbeat on GPIO48

Three boards blinking, click for video

Pin walk on board 1. The first pin in the list pulses once, the second
twice, and so on, then every pin is read back with the pull-up on.
26 pins, four batches of eight on the logic analyzer, every count
matched the schematic header. GPIO43 and 44 are the TX and RX pads
on the silkscreen, not numbered.

First read pass came back with random 0s. I was reading right after
turning on the 45k pull-up, and the pin had just been driven low, so it
hadn't charged yet. Pull-ups on for everything, 10 ms settle, then read:
all 1s every pass.

Each batch: analyzer GND to header 22, D0 to D7 on eight header pins,
1 MHz capture. Counting the pulses on a channel tells you which GPIO
is on that pin.

Board 1 wired to the analyzer, batch 1

Batch 1:

| Ch | Header | GPIO | Signal | Pulses | Seen |
|---|---|---|---|---|---|
| D0 | 4 | 4 | ENC1_A | 1 | ✓ |
| D1 | 5 | 5 | ENC1_B | 2 | ✓ |
| D2 | 6 | 6 | ENC1_SW | 3 | ✓ |
| D3 | 7 | 7 | ENC2_A | 4 | ✓ |
| D4 | 12 | 8 | ENC2_B | 5 | ✓ |
| D5 | 15 | 9 | ENC2_SW | 6 | ✓ |
| D6 | 8 | 15 | CH2_SCLK | 7 | ✓ |
| D7 | 9 | 16 | CH2_SDO | 8 | ✓ |

Batch 1: 1 to 8 pulses

Batch 2:

| Ch | Header | GPIO | Signal | Pulses | Seen |
|---|---|---|---|---|---|
| D0 | 10 | 17 | CH2_CS | 9 | ✓ |
| D1 | 16 | 10 | CH1_CS | 10 | ✓ |
| D2 | 11 | 18 | ENC3_A | 11 | ✓ |
| D3 | 18 | 12 | CH1_SCLK | 12 | ✓ |
| D4 | 19 | 13 | CH1_SDO | 13 | ✓ |
| D5 | 27 | 21 | ENC3_B | 14 | ✓ |
| D6 | 35 | 38 | ENC3_SW | 15 | ✓ |
| D7 | 36 | 39 | BTN_RUN | 16 | ✓ |

Batch 2: 9 to 16 pulses

Batch 3:

| Ch | Header | GPIO | Signal | Pulses | Seen |
|---|---|---|---|---|---|
| D0 | 37 | 40 | BTN_SINGLE | 17 | ✓ |
| D1 | 38 | 41 | BTN_GEN | 18 | ✓ |
| D2 | 39 | 42 | LED_RUN | 19 | ✓ |
| D3 | 28 | 47 | LED_TRIG | 20 | ✓ |
| D4 | 41 | 1 | LED_ARM | 21 | ✓ |
| D5 | 43 (TX) | 43 | LINK1_TX | 22 | ✓ |
| D6 | 42 (RX) | 44 | LINK1_RX | 23 | ✓ |
| D7 | 40 | 2 | spare | 24 | ✓ |

Batch 3: 17 to 24 pulses, TX and RX included

Batch 4:

| Ch | Header | GPIO | Signal | Pulses | Seen |
|---|---|---|---|---|---|
| D0 | 17 | 11 | spare | 25 | ✓ |
| D1 | 20 | 14 | spare | 26 | ✓ |

Batch 4: the two spares, 25 and 26

Pin walk on board 2. Same 26-pin idea, same header order as board 1, so
the analyzer wiring for each batch didn't change between boards. Every
count matched. GPIO48 stays off the list: it's the status LED now and
the touch reset later, so it gets checked when the touch panel goes on.

Batch 1:

| Ch | Header | GPIO | Signal | Pulses | Seen |
|---|---|---|---|---|---|
| D0 | 4 | 4 | LCD_R5 | 1 | ✓ |
| D1 | 5 | 5 | LCD_R6 | 2 | ✓ |
| D2 | 6 | 6 | LCD_R7 | 3 | ✓ |
| D3 | 7 | 7 | LCD_G2 | 4 | ✓ |
| D4 | 12 | 8 | LCD_G3 | 5 | ✓ |
| D5 | 15 | 9 | LCD_G4 | 6 | ✓ |
| D6 | 8 | 15 | LCD_B5 | 7 | ✓ |
| D7 | 9 | 16 | LCD_B6 | 8 | ✓ |

Board 2 batch 1: 1 to 8 pulses, red and green data lines

Batch 2:

| Ch | Header | GPIO | Signal | Pulses | Seen |
|---|---|---|---|---|---|
| D0 | 10 | 17 | LCD_B7 | 9 | ✓ |
| D1 | 16 | 10 | LCD_G5 | 10 | ✓ |
| D2 | 11 | 18 | LCD_DCLK | 11 | ✓ |
| D3 | 18 | 12 | LCD_G7 | 12 | ✓ |
| D4 | 19 | 13 | LCD_B3 | 13 | ✓ |
| D5 | 27 | 21 | LCD_HSYNC | 14 | ✓ |
| D6 | 35 | 38 | LCD_VSYNC | 15 | ✓ |
| D7 | 36 | 39 | LCD_DE | 16 | ✓ |

Board 2 batch 2: 9 to 16 pulses, the rest of the RGB bus and its sync lines

Batch 3:

| Ch | Header | GPIO | Signal | Pulses | Seen |
|---|---|---|---|---|---|
| D0 | 37 | 40 | TOUCH_SDA | 17 | ✓ |
| D1 | 38 | 41 | TOUCH_SCL | 18 | ✓ |
| D2 | 39 | 42 | TOUCH_INT | 19 | ✓ |
| D3 | 28 | 47 | LINK2_TX | 20 | ✓ |
| D4 | 41 | 1 | LCD_R3 | 21 | ✓ |
| D5 | 43 (TX) | 43 | LINK1_TX | 22 | ✓ |
| D6 | 42 (RX) | 44 | LINK1_RX | 23 | ✓ |
| D7 | 40 | 2 | LCD_R4 | 24 | ✓ |

Board 2 batch 3: 17 to 24 pulses, touch, both links, two red lines

Batch 4:

| Ch | Header | GPIO | Signal | Pulses | Seen |
|---|---|---|---|---|---|
| D0 | 17 | 11 | LCD_G6 | 25 | ✓ |
| D1 | 20 | 14 | LCD_B4 | 26 | ✓ |

Board 2 batch 4: 25 and 26

Pin walk on board 3. Only nine pins: the eight R-2R bits and LINK2's
receive line. The DAC bits are the ones that have to be exact, since
all eight get written in one store to GPIO_OUT later. All eight matched,
and LINK2_RX on the RX pad showed its 9 pulses. Pin walk done on all
three boards, 61 pins, no mismatches.

| Ch | Header | GPIO | Signal | Pulses | Seen |
|---|---|---|---|---|---|
| D0 | 4 | 4 | DAC_D0 | 1 | ✓ |
| D1 | 5 | 5 | DAC_D1 | 2 | ✓ |
| D2 | 6 | 6 | DAC_D2 | 3 | ✓ |
| D3 | 7 | 7 | DAC_D3 | 4 | ✓ |
| D4 | 12 | 8 | DAC_D4 | 5 | ✓ |
| D5 | 15 | 9 | DAC_D5 | 6 | ✓ |
| D6 | 16 | 10 | DAC_D6 | 7 | ✓ |
| D7 | 17 | 11 | DAC_D7 | 8 | ✓ |
| D0 (batch 2) | 42 (RX) | 44 | LINK2_RX | 9 | ✓ |

Board 3 batch 1: the eight DAC bits, 1 to 8 pulses

Board 3 batch 2: LINK2_RX, 9 pulses

## 2026-09-23

Wrote the SPI side for the ADCs: GP-SPI2 set up straight from its
registers, no driver. Clock on, pins on the IO MUX, 80 MHz module clock
divided down, mode 1, 16 clocks per frame, single or dual line. The
fastest legal clock is 26.67 MHz (80 MHz / 3), since /2 would be 40 and
the ADS7883 tops out at 32 at 3.3 V.

Speed test is written too: times 10,000 frames on the cycle counter for
five settings and holds each for 2 s so the analyzer can catch it.
Nothing plugged in yet, the analyzer run is next.

## 2026-09-24

Ran the speed test on board 1. JTAG flashing kept failing in OpenOCD,
so flashed over UART on COM7 instead.

First run tripped the task watchdog: the 2 s hold loop spun and IDLE0
never ran. It yields every 500 frames now. The result lines also went
missing until I added a 10 ms delay after unmasking interrupts, plus
fflush.

| SCLK | Mode | Lines | Cycles/frame | ns/frame | kSa/s |
|---|---|---|---|---|---|
| 10 MHz | 1 | single | 525 | 2188 | 457 |
| 10 MHz | 1 | dual | 525 | 2188 | 457 |
| 26.67 MHz | 0 | single | 261 | 1088 | 919 |
| 26.67 MHz | 1 | single | 261 | 1088 | 919 |
| 26.67 MHz | 1 | dual | 261 | 1088 | 919 |

At 26.67 MHz the 16 clocks take 600 ns, so about 490 ns of each frame
is overhead from the CPU starting each frame. DMA fixes that later.
Dual line costs nothing, so it's Plan B: one SCLK and CS for both ADCs,
CH1 on GPIO13, CH2 on GPIO11.

Speed test output on the monitor

Analyzer on board 1, 24 MHz sample rate:

| Analyzer | GPIO | Signal |
|---|---|---|
| D0 | 12 | SCLK |
| D1 | 10 | CS |

Analyzer wired to board 1

Five frames back to back

10 MHz: CS period 2208 ns, matches the 2188 from the cycle counter.
16 clocks per frame.

10 MHz block, 16 clocks inside one CS low

26.67 MHz: CS period 1084 ns, matches 1088. The clock itself aliases at
24 MHz sampling, so the CS period is the proof here, not the edges.

26.67 MHz block, CS period

The analog rail. MCP1700 on the breadboard, 1 uF ceramics for
C1 and C2 from the MLCC kit, jumper wire for R1. Nothing else on
+3V3_A yet.

+5V comes from the ELEGOO breadboard power module for now instead of
board 1's 5V pin, so the USB backfeed check is skipped. Its USB-C input
only gave 4.648 V (passthrough plus the drops along the way). The
barrel jack goes through the module's own regulator and gives 4.987 V,
so that's what I'm using.

| Node | Reading |
|---|---|
| +5V_A (VIN) | 4.987 V |
| +3V3_A (VOUT) | 3.314 V |

3.314 V is 0.4% high, well inside the MCP1700's +/-3% spec.

+5V_A from the barrel jack

+3V3_A at the MCP1700 output

The 2.2 V reference. R2/R3 (10k/20k) off +3V3_A with C3 on
the midpoint, U2A as a unity-gain buffer, C4 right on pin 8. U2B is
parked as a follower with its input on GND, same as the schematic.

| Node | Reading |
|---|---|
| Divider (pin 3) | 2.214 V |
| VREF_2V2 (pin 1) | 2.214 V |

Expected 3.314 x 20k/30k = 2.209 V, so 5 mV off, inside 1% resistor
tolerance. Pin 1 matches pin 3, so the buffer adds nothing.

VREF_2V2 at the buffer output

Prep for the front end: the parts that don't fit a breadboard.

BNCs (Superbat panel mount) got jumper wires soldered on: centre pin for
signal, solder lug for ground. Continuity centre to jack pin and lug to
barrel beep, centre to shell reads OL.

BAV99s are SOT-23-3, so they went on the adapter boards. Tiny and
sloppy without proper tools, but continuity passes. The adapter
silkscreen doesn't match the part:

| BAV99 pin | Job | Adapter pad |
|---|---|---|
| 1 | lower anode, to GND | 6 |
| 2 | upper cathode, to +3V3_A | 2 |
| 3 | common, to JCT | 4 |

One of the two has pins 2 and 3 bridged. That shorts the upper diode
and ties JCT straight to +3V3_A, so it's not going in until the bridge
is cleaned up.

BNC with soldered leads, continuity

BNCs and BAV99 adapters, continuity

BAV99s on their adapters

CH1 front end on the breadboard: R4 750k, R5 250k to VREF_2V2, BAV99
clamp, U3A buffer. Trimmers and the ADC filter stay off for now. Output
measured at U3 pin 1.

| Input | Expected | Measured |
|---|---|---|
| Nothing connected | 2.21 V (no current, so it sits at VREF) | 2.2 V |
| IN to GND | 1.66 V (0.75 x VREF) | 1.66 V |

Input open, output at VREF

Input grounded, output at the 1.66 V offset

CH2 front end, same circuit: R7 750k, R8 250k to VREF_2V2, the second
BAV99, U4A buffer. Output measured at U4 pin 1.

| Input | Expected | Measured |
|---|---|---|
| Nothing connected | 2.21 V | 2.21 V |
| IN to GND | 1.66 V | 1.66 V |

Both channels match each other and the math.

CH2 input open, output at VREF

CH2 input grounded, output at the 1.66 V offset

## 2026-09-25

Front panel on board 1: three LEDs and three buttons on their own
breadboard, wired to the board's headers.

Moved LED_TRIG from GPIO47 to GPIO2 first. There was no reason for it
to sit apart from the other two, and now the LEDs are on headers 39-41
right above the buttons on 36-38. Schematic, pin map and pin header
updated together.

| Part | GPIO | Header | Notes |
|---|---|---|---|
| LED_RUN (green) | 42 | 39 | 330R, active high |
| LED_TRIG (yellow) | 2 | 40 | 330R, active high |
| LED_ARM (red) | 1 | 41 | 330R, active high |
| BTN_RUN | 39 | 36 | to GND, internal 45k pull-up |
| BTN_SINGLE | 40 | 37 | to GND, internal 45k pull-up |
| BTN_GEN | 41 | 38 | to GND, internal 45k pull-up |

panel.c polls all six inputs (the three buttons plus the encoder
switches) every 1 ms and only takes a change after 20 scans in a row
agree, so bounce never gets through. Each clean press or release goes
on a FreeRTOS queue as an event. Polling instead of edge interrupts:
the 20 ms debounce sets the response time either way, and a bouncing
contact would fire dozens of interrupts per press.

The test prints every event and toggles an LED per button. One press
and one release per push, no doubles.

Panel test running, events on the monitor

[Video: buttons toggling the LEDs](screenshots_videos/panel_buttons_leds_test.MP4)

Put the dual-line SPI decision into the schematic and pin map. Both
ADCs now share one clock and one chip select on SPI2's IO MUX pins, and
CH2's data comes in on GPIO11 (FSPID) next to CH1's on GPIO13 (FSPIQ).
The old second bus on GPIO15-17 is gone, and so is R11: one 10k pull-up
on the shared CS covers both converters.

That freed three pins right where the encoders were scattered, so the
encoders moved too. All nine encoder lines now sit on headers 4-12, one
knob after another.

| Signal | Was | Now | Header |
|---|---|---|---|
| ADC_SCLK | 12 (CH1) + 15 (CH2) | 12 | 18 |
| ADC_CS | 10 (CH1) + 17 (CH2) | 10 | 16 |
| CH1_SDO | 13 | 13 | 19 |
| CH2_SDO | 16 | 11 | 17 |
| ENC2_B | 8 | 15 | 8 |
| ENC2_SW | 9 | 16 | 9 |
| ENC3_A | 18 | 17 | 10 |
| ENC3_B | 21 | 18 | 11 |
| ENC3_SW | 38 | 8 | 12 |

Spares now 9, 14, 21, 38, 47. Nothing was wired to the old pins yet, so
this is paper only, the encoders get checked on the new pins when they
count.

Three EC11 encoders on the panel breadboard, on the new pins (headers
4-12). Each one: A and B to their GPIOs, the middle pin C to GND, push
switch between its SW GPIO and GND. Internal pull-ups, no extra parts.

The decoder is a 16-entry table indexed by the last and current A/B
state, run in the same 1 ms scan as the buttons. A legal step gives +1
or -1, no change or an illegal jump gives 0. Contact bounce toggles one
line back and forth, which reads as +1, -1, +1, -1 and cancels, so
there's no separate debounce. Four steps make one detent on these
(one full A/B cycle per click), and only whole detents become events.

One click prints enc1 +1, back prints enc1 -1, on all three knobs.
The knob presses come through the button code as ENC1-3 press/release.

Encoders, buttons and LEDs on the panel breadboard

[Video: turning and pressing the knobs](screenshots_videos/panel_encoders_test.MP4)

## 2026-09-26

Soldered both ADS7883s onto SOT23-6 adapters. Took about four hours,
with no magnifier, no clamps or helping hands, and 0.8 mm solder, which
is too thick for 0.95 mm pitch. Lost two chips along the way, two made
it, which is what the design needs.

What finally worked: tin one corner pad only, hold the chip with
tweezers, reflow that blob to tack one leg, then do the opposite
corner, then the rest. Once one leg is down the chip stops moving.
Headers went on first with the breadboard as a jig, chip after.

Checks on both boards, nothing powered yet:

- Continuity from every chip leg to its header pin: all six pass.
- Adjacent pins shorted: none.
- Orientation from the diode test on the first chip: pin 2 conducts to
  every other pin with the red probe on it, so it's GND and the chip
  is the right way round.

Next time: 0.5 mm solder, tacky flux paste and fine tweezers.

Soldering setup

First ADS7883 on its adapter, next to a bare SC70 one

Both ADS7883 adapters, continuity checks

Wired both ADCs into the front ends. U6 on CH1, U7 on CH2, sharing
SCLK (IO12) and CS (IO10), data on IO13 and IO11. R6/R9 are two 330R in
parallel (165R) instead of 150R, still under the ADS7883's 200R source
limit. C8/C9 and C13/C14 (2.2 nF) are on each ADC input. Trimmers and
BNCs still off, IN is a jumper for now.

Both chips are soldered 180 degrees round on their adapters, so the
silkscreen is off by three: chip pins 1-6 are silk 4, 5, 6, 1, 2, 3.
Wired by chip pin, not silkscreen.

First read with the single-line test: code 0.0 on every frame, which
prints as -6.644 V at the BNC. The firmware checks out, and 0 is what
the ADC should report for 0 V in, so the problem is upstream. VREF
wasn't connected to the dividers at first, with that fixed, the R4/R5
junction reads 1.63 V as expected, but VIN at the ADC was still near
0 V. Swapping the two ADCs gave the same result. Still tracing.

Setup for the first ADC read

Monitor stuck at code 0

Found one: SCLK and CS were swapped on the breadboard. The ADC was being
clocked on its CS pin and selected by the clock, so it never produced a
real frame. With them swapped back the codes move off zero (about 25,
with some frames near 88), so the SPI link is alive. Still well under
the ~2000 expected for 1.63 V in, so VIN is next.

Codes off zero after the SCLK/CS fix

Printed every raw frame instead of the average. About a third of the
frames were wrong, and always the same way: the good code shifted left
one bit (2059 came back as 22). The ADC was one clock ahead, like it
counted an extra SCLK edge right after CS fell.

Put the logic analyzer on it. Two things in the captures: the PulseView
decoder has to match the ADC (mode 0, CS active-low) or it shows garbage
of its own, and the shifted frames were really on the wire. On a bad
frame both SDO lines flick high for about 40 ns after the first falling
edge, then drop, so both chips stepped twice on one edge.

Decoder in mode 1: frames shifted

Decoder in mode 0: good and shifted frames mixed

Tried, in order:

- SPI mode 1 to mode 0. No real change.
- One clock of CS setup before the first SCLK. Bad frames went from 35%
  to 9%.
- 50R in series with SCLK. Worse, about half the frames bad.
- New jumper, rerouted. Still about 40%.
- Unplugged the logic analyzer. Zero bad frames.

The analyzer was the problem. Its leads on the shared SCLK line plus its
ground going back through USB were enough to make both ADCs double
count a clock edge. The 9% run was the only one taken before it was
clipped on. Lesson: the probe is part of the circuit.

With it off: clean at 4 MHz and at 10 MHz, both channels. Checked CH2 by
moving its SDO wire onto IO13 and touching its input to VREF (code jumps
to about 2720). Kept the CS setup delay, dropped the resistor.

Bench while chasing it

Raw frames at 10 MHz, all good

Last bit was calibration. With IN grounded the ADC reads 2067, which is
1.672 V against a 3.314 V supply, not the 1.661 V I'd assumed. Set the
offset to the measured value and the BNC reading sits at 0.001 V,
steady to one code.

Calibrated: 0.001 V at the BNC with IN grounded

## 2026-09-27

Noise floor at full speed. SCLK at 26.67 MHz, IN grounded, 16384
samples per run, both SPI modes back to back.

Both modes were clean over about 100k samples, no bit-slips, and the
noise is the same: about 4 codes rms, 13 mV at the BNC. Went with mode 1
anyway. At this clock the ADC's data can show up 20 ns after the falling
edge, and mode 0 samples 18.75 ns after it, so mode 0 has negative
worst-case margin on paper. Mode 1 samples a full clock later.

Mode 0 and mode 1 side by side on the monitor

Bench during the noise test

Dumped one run to the PC for a histogram. First try came back with a
third of the lines missing and one corrupted value (061 instead of
2061) that dragged the rms to 19 codes. The board was printing faster
than the USB console could drain. A 10 ms pause every 128 lines fixed
it, and the capture script now rejects anything short or malformed.

Histogram, 16384 samples, IN grounded

Most samples sit within 4 codes of the mean. The rms is pulled up by a
few lone samples 40 to 60 codes out, which looks like pickup on the
breadboard rather than the ADC. The filter as built (165R and 4.4 nF)
puts the corner at about 219 kHz.

The mean at 26.67 MHz is about 2062, 5 codes lower than at 10 MHz, so
the offset calibration has to be done at the speed it runs at.

Both channels in one read. The two ADCs share SCLK and CS, and CH2's
data comes in on the second SPI data line, so one 16-clock frame
brings in 32 bits with the two channels interleaved bit by bit. A
five-step shift-and-mask pulls every other bit back together.

Moved the ADC frame decoding into its own header with no ESP-IDF
includes, so the same code builds on the PC. The host test interleaves
two known words the way the hardware does and checks the fast split
against a plain bit-by-bit loop on 10,000 random pairs.

Host tests passing on the PC

On the board, both inputs grounded at 26.67 MHz: CH1 about 2062, CH2
about 2069. The 7-code gap (about 24 mV at the BNC) is steady, so it's
an offset between the two front ends, and it gets calibrated per
channel. CH1 in the dual read matches CH1 read on its own at the same
speed, so the channels aren't swapped.

Both channels from one frame, inputs grounded

Burst capture with DMA. Until now every sample was the CPU starting an
SPI frame and waiting for it. Now the SPI block and the DMA engine run
a whole burst on their own: a list of 3200 small segments, each one a
full ADC frame, with the gap between frames set by a hardware counter
in 12.5 ns steps. The CPU starts the burst, sleeps, and gets one
interrupt at the end.

To check the timing I needed a signal I trust, so board 1 makes its
own: a 1 kHz square from the LEDC peripheral on a spare pin, jumpered
into CH1's input. Samples per period tells you the real sample rate.

Burst rates on the monitor

100 kSa/s measured 100.26 k, 20 kSa/s measured 20.01 k. The CS-low
part of each segment turned out much longer than the 51 clocks the
math gives, about 124 at the bus clock, because each segment also has
to load its setup from memory. That puts the ceiling at about 620 kSa/s,
not the 1.43 M I'd worked out on paper.

First 3 ms of a burst at 100 kSa/s

The square comes through clean, about 2075 to 3090, with an edge
spread over one or two samples from the front end and the anti-alias
filter.

Reran the noise test with all of this wired up, and this time mode 0
fell apart at 26.67 MHz: minimums down around 20 and 35 to 50 codes
rms, the same bit-slip pattern as before. Mode 1 stayed at about 4
codes. Earlier both modes were clean, so mode 0 was sitting right on
the edge, which is exactly what the timing math said. Glad I went with
mode 1.

Mode 0 slipping, mode 1 clean

Trigger. It scans a capture for the first point where the signal
crosses a level in the chosen direction, so a repeating waveform lands
in the same place every frame instead of sliding across the screen.
Two things make it usable on real signals: hysteresis, where the signal
has to drop clearly below the level before a rising crossing counts, so
noise sitting on the level can't fire it, and a sub-sample position,
interpolated between the two samples on either side of the crossing,
so the trace doesn't jump by a whole sample from frame to frame.

It's pure C, so it's tested on the PC: exact crossing on a clean sine,
a crossing 0.3 samples between two points, chatter at the level ignored,
falling edge, and a noisy sine that still triggers once per period. All
three host test suites pass.

Host tests, trigger added

## 2026-09-28

Decimation. A capture has more samples than the screen has columns, so
each of the 800 columns has to stand for a group of samples. Averaging
or picking one sample per group would make a short glitch vanish. So
each column keeps both the lowest and the highest sample in its group,
and the screen draws a line between them. A spike one sample wide still
shows up.

Also pure C and host-tested: a one-sample spike survives, constant input
stays constant, 800 samples into 800 columns comes out unchanged, and a
ramp whose length isn't a multiple of 800 has every sample land in
exactly one column with no gaps. All four host test suites pass.

Host tests, decimation added

How the trigger and decimation work, drawn out: frames lining up on the
rising edge, hysteresis stopping noise at the level from firing it
again, the crossing placed between two samples, and min/max keeping a
one-sample glitch that averaging would shrink.

Trigger and min/max decimation explained

How capture actually runs. Each burst is one-shot: the CPU starts it,
the DMA fills 3200 samples on its own, the SPI block stops after the
last segment and fires one interrupt. Then the CPU triggers, decimates
and sends the frame, and only then starts the next burst. Whatever the
signal does in between is never recorded. That's dead time, and every
digital scope has it, the spec is called waveform update rate.

Burst coverage, the capture loop, and a damped signal

How much of the signal one burst holds depends on the ratio of signal
frequency to sample rate: cycles = f x 3200 / fs. A 1 kHz sine at
100 kSa/s is 32 cycles, at 620 kSa/s about 5. Frames are never stitched
together, so a one-time event like a damped oscillation has to fit
inside a single burst: slow the sample rate until it does, and use
single-shot so it's captured once and held.

Could the dead time go away? Checked the TRM (30.5.8.5): the segmented
transfer keeps going as long as each segment's CONF sets
usr_conf_nxt = 1, and my last segment clears it on purpose. Loop the
descriptor chains back to the start and set it everywhere, and it
should run as a continuous ring at the same data rate a burst already
proves. The catch is knowing when half the ring is full: the SPI
done interrupt only fires at the end, which never comes, and the GDMA
per-descriptor interrupt would fire on every sample. It would need a
timer or polling. And the screen only shows about 30 frames a second
out of roughly 190 bursts, so it only pays off for something like a
glitch search over every burst. Staying with one-shot for now, the
ring is a later experiment, untested.

Acquisition task. Board 1 now runs on its own: a FreeRTOS task pinned
to core 1 loops capture, trigger, min/max, and builds the frame that
will go to the display board. A settings struct under a mutex holds the
rate, trigger level, edge and source, and RUN/STOP/SINGLE, so the panel
buttons (and later the display board) can change it safely from other
tasks. AUTO mode shows an untriggered frame after three missed bursts,
so a flat line still draws instead of freezing.

Default rate is 320 kSa/s (500 us/div at 1600 samples). 800 kSa/s for
200 us/div was the plan on paper, but it's above the 620 kSa/s I
measured, so at full record length that setting is out.

With the 1 kHz bench signal on CH1: 70 frames/s, every frame triggered,
0 errors, about 2 KB of the task's 4 KB stack left. One burst is
3200 samples at 320 kSa/s, 10 ms, so the ceiling is 100 frames/s, 70
means about 4 ms per frame of trigger, decimation and re-arming the
burst, roughly 30% dead time. RUN stops and restarts with all three
LEDs following, SINGLE captures one frame and holds.

Stats line: 70 frames/s, every frame triggered, no errors

Board 1 running on its own, RUN, TRIG and ARM lit

Link protocol. Board 1 has to send frames to board 2 over a UART, and a
UART only moves bytes: no message boundaries, no error check, no way to
find your place if you start listening mid-stream. Each message is now
type, sequence number, length, payload and a CRC-16, then COBS-encoded
so the byte 0x00 never appears inside it, then a single 0x00 to end it.
The receiver collects bytes until 0x00, decodes and checks the CRC,
after garbage it just waits for the next 0x00 and is back in sync. A
jump in sequence number counts as a lost frame. Pure C, host-tested: the
published CRC check value, COBS at its awkward lengths (253, 254, 255),
a flipped bit caught, garbage ignored, a missing frame counted.

UART driver, written from the registers: UART1 on GPIO43/44 through the
GPIO matrix, an interrupt handler and a ring buffer each way. Tested in
loopback, a 220R from TX back to RX on board 1, sending frames of random
length up to 7 KB at 2 Mbaud. 15,600 frames in about 4.5 minutes, every
one intact, zero CRC, length, framing, overflow or dropped-byte errors.
About 55 frames a second of 3.6 KB average, so the wire is running at
full speed. The ring buffer is host-tested too, and all six host test
suites pass.

Six host test suites passing

UART loopback: 15,600 frames at 2 Mbaud, no errors

Loopback on the bench, LINK1 pins on the schematic

Board 1 to board 2. The two boards are now wired to each other: each
TX through a 220R to the other's RX, grounds joined. Board 1 sends every
decimated frame (a 64-byte header plus min and max for both channels,
6.5 KB) and every panel event, board 2 sends pings and settings back,
and board 1 answers settings with its run state and actual sample rate.
One shared header defines every message so all three boards agree.

About 31.8 frames/s arrive, which is what 2 Mbaud allows for 6.5 KB
frames, with zero CRC, length or dropped-byte errors. Every encoder
turn, press and release shows up on board 2. RUN reports STOP, SINGLE
reports SINGLE then STOP after one frame, and a settings change from
board 2 comes back confirmed. Ping round trip is about 40 ms because a
ping waits behind a frame that takes 33 ms to send.

The COBS and framing errors in the screenshot are from unplugging. With
one board unpowered, the other kept driving its RX pin, which back-powers
the dead chip through its pin, it then came up with a stuck USB port
until reset. The counts stay flat while both run, so no new errors. The
220R resistors are there to keep that current small. Rule for the bench:
power both boards together, or reset the one plugged in last.

Both monitors: frames, keys and state messages

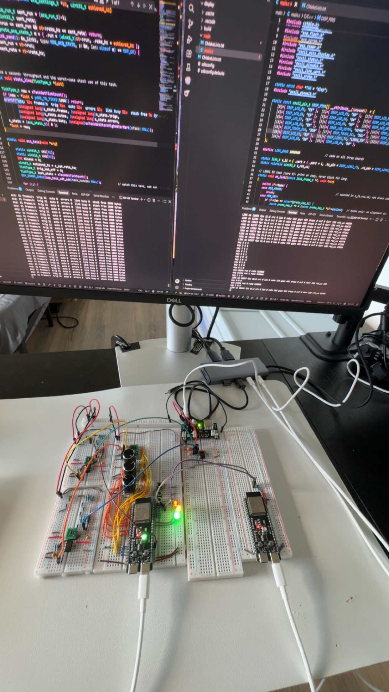
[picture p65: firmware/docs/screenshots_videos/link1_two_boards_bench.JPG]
Board 1 and board 2 on the bench, crossed LINK1


[Video: LEDs and keys with the link running](screenshots_videos/link1_leds_keys_demo.MP4)

Display prep. Soldered header pins onto the four display boards: the
Adafruit 40-pin TFT breakout for the panel ribbon, the 6-pin FPC
adapter for the touch ribbon, the XL6009 boost for the backlight and
the 5 V input. Beeped every pad against its neighbour for shorts and
against the pin it should reach. All clean.

Mapped the breakout against Adafruit's schematic before wiring anything.
The silkscreen matches this panel's RGB, clock, sync, DE and DISP pins,
but three things differ. The breakout ties ribbon pins 3 and 36 to
ground and leaves 35 open, on this panel those are the SPI chip select,
data and clock, so the panel runs its default RGB mode and the CS/SPI
tie-offs on my schematic are left out. The LA pad has a 24 V clamp
diode across the LED string for the breakout's own driver, this
backlight needs 25.6 V, so the diode comes off before the XL6009 drives
it. And 5VIN powers the breakout's boost chip, so it stays unconnected.

First fit the ribbon went in flipped and every pin came out mirrored
(pin 1 on YU). Caught it with the meter before powering anything.

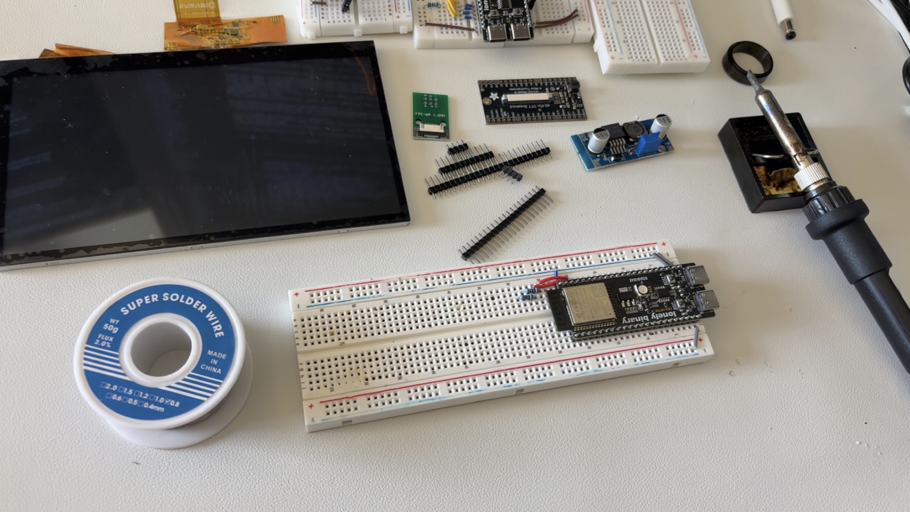
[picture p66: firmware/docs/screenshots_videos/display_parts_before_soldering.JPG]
Parts laid out before soldering


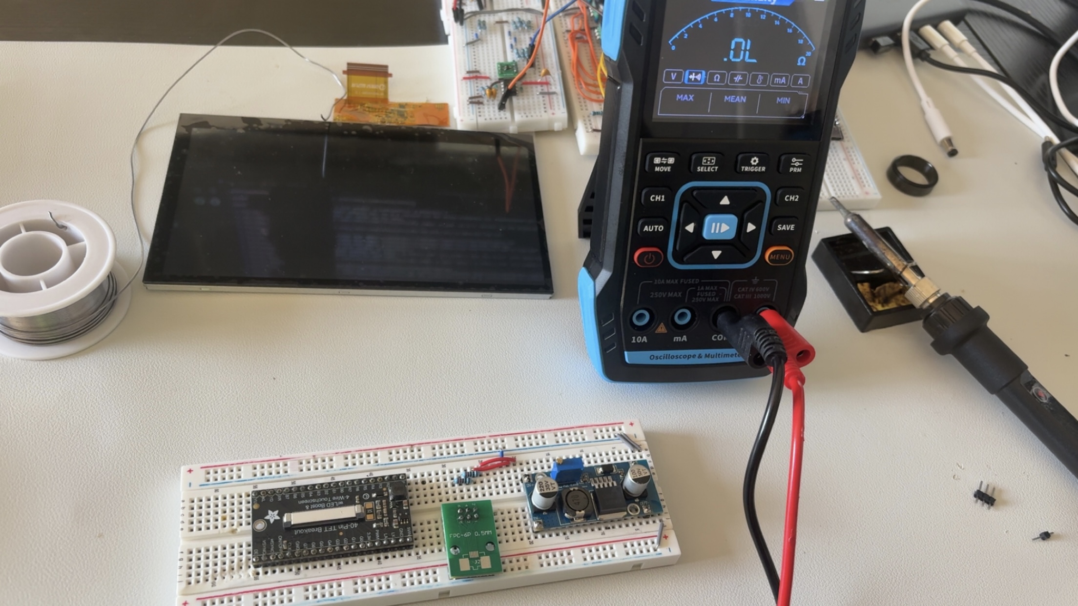
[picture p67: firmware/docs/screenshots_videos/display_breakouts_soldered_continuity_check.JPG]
Breakouts soldered, continuity and short check


Backlight, alone. Set the XL6009 with nothing on its output first: it
turns down to about 5 V (a boost can't go below its input) and up past
22 V, so the module regulates. Parked it at 20 V, below where the LED
string turns on. Then wired OUT+ through a 100R to LA and LK to ground,
and crept the trimpot up with the meter across the resistor.

Almost no current at first, then it came up fast once the string
turned on, the knee 8 LEDs in series predict. At 25.5 V out it was
3.0 V across the 100R (30 mA). Stopped at 4.0 V across the 100R:
40 mA, two thirds of the rated 60 mA and well under the 75 mA maximum.
The booster reads 27 V, so the string drops about 23 V. Used 100R
instead of the schematic's 75R (the resistor kit has no 75R), it
dissipates 0.16 W at 40 mA, inside its rating.

The breakout's own 24 V clamp sits across the string. At 23 V it stays
below its threshold, and after a minute everything on the breakout was
cool, so it stayed on the board. Nothing else of the panel is connected
yet, so the glow is plain white.

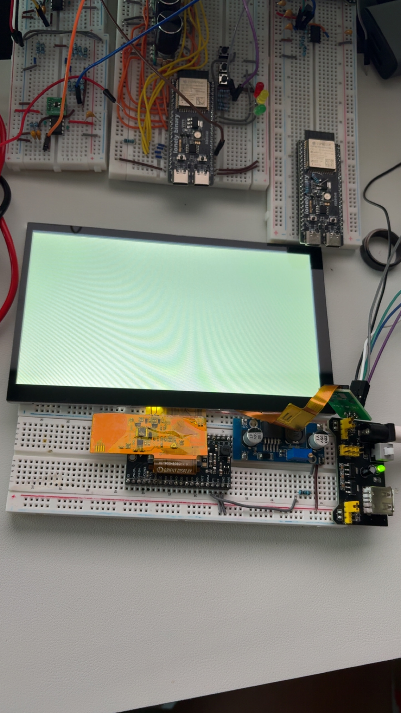
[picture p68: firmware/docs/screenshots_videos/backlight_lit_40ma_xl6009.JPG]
Backlight lit at 40 mA from the XL6009


Colour bars, first attempt. Before wiring, reordered board 2's LCD pins
so the left header runs in the breakout's pad order: reds, then all five
blues, then all six greens, then the pixel clock. The LCD peripheral
reaches its pins through the GPIO matrix, so any free pin can carry any
bit, same 27 GPIOs, only the labels and the pin header changed. Wired
the 16 data lines, clock, HSYNC, VSYNC and DE, tied the unused low bits
(R0 to R2, G0, G1, B0 to B2) to ground and ON/OFF high through 10k. The
breakout already grounds the panel's SPI chip select and data pins, so
the CS/SPI tie-offs on my schematic have nowhere to go and are left
out. Touch ribbon wired too, with 2k pull-ups on SCL and SDA for margin.

The firmware side is up: the panel driver starts at 800 x 480, 16 MHz
pixel clock, 32.8 Hz refresh, and the test cycles bars, bits and border.
The panel stays plain white, which is what it shows with backlight but
no working logic. Next: DC-check the 3.3V, GND, ON/OFF, CLK (should
average about half the rail), HSYNC, VSYNC and DE pads, and reseat the
ribbon.

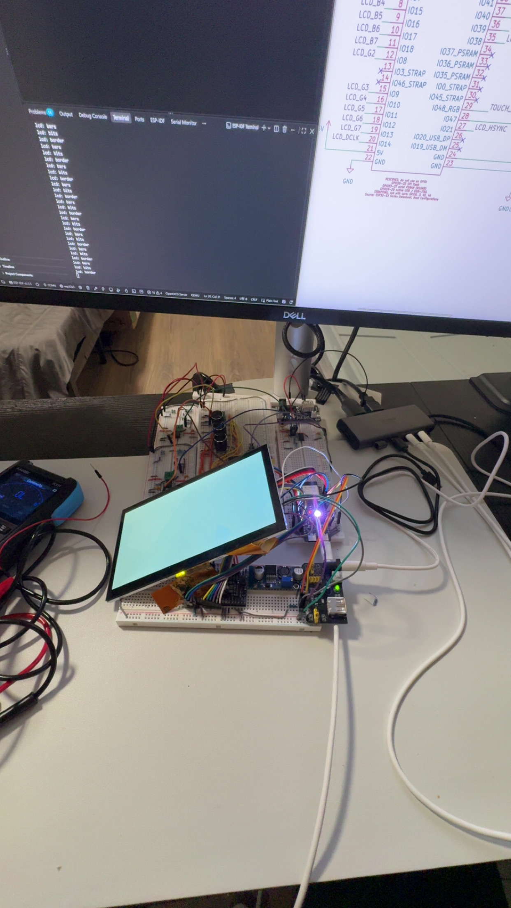
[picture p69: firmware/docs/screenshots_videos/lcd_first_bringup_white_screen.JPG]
First bring-up: test running, panel still white


What it should show, drawn from the test code: colour bars, then one band
per data wire (dim to bright blue, green, red), then a 1-pixel border.

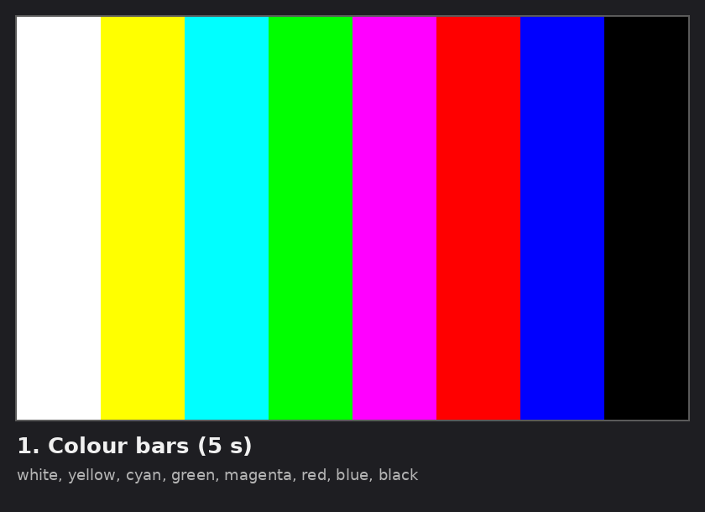
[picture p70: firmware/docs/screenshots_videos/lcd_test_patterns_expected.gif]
Expected test patterns


## 2026-09-29

Colour bars, fixed. The white screen was power, not signals. The panel's
3.3 V read 2.3 V off the breadboard supply, below its 2.7 V minimum, and
the supply's parts ran hot. Moving the panel to board 2's own 3.3 V (as
the schematic has it) dragged that rail to 2.2 V too, so something on
the breakout was loading it.

Adafruit's schematic explains it. The breakout's 3.3V pad is the output
of its own small regulator, whose input is 5VIN. Feeding 3.3 V into that
pad leaks back through the regulator onto 5VIN, and 5VIN also powers
the breakout's backlight boost chip, whose enable pin (PWM) is pulled up
to 5VIN. So the boost chip switched itself on and pulled hard on my
3.3 V rail. Tied PWM to ground to hold it in shutdown, left 5VIN
unconnected, and the rail holds at 3.3 V.

Now the panel's logic, touch, pull-ups and ON/OFF all run from board 2's
3.3 V, so the panel switches on and off with the board, and the backlight
stays on its own 5 V through the XL6009. Colour bars come up, and the
test cycles through the bit bands and the border.

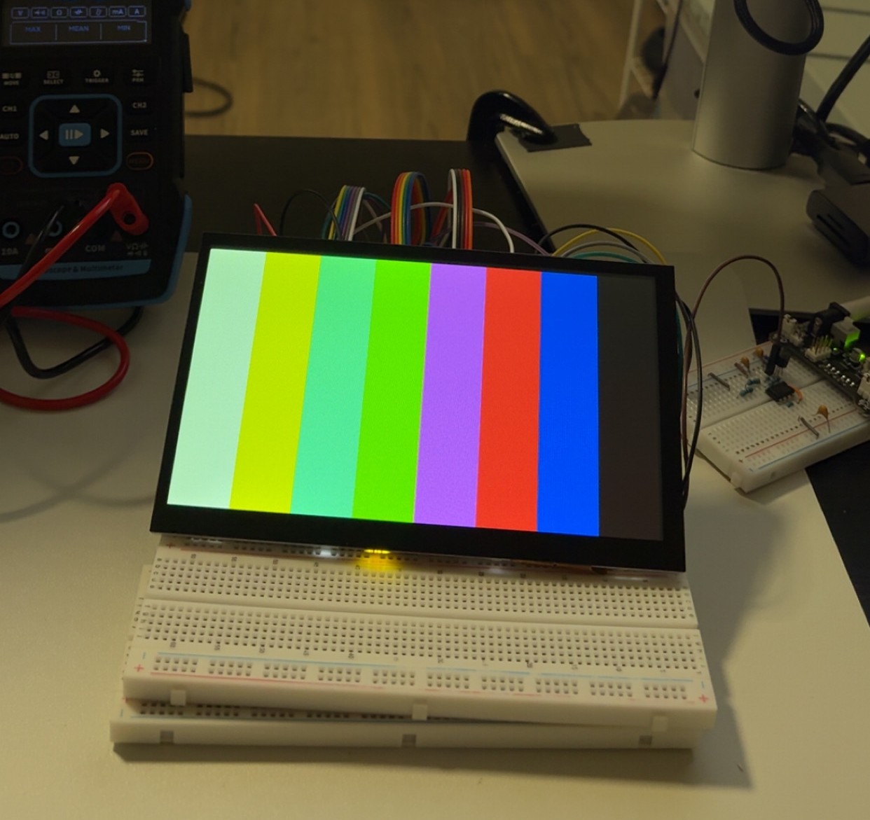
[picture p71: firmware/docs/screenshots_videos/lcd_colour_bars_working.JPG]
Colour bars on the panel


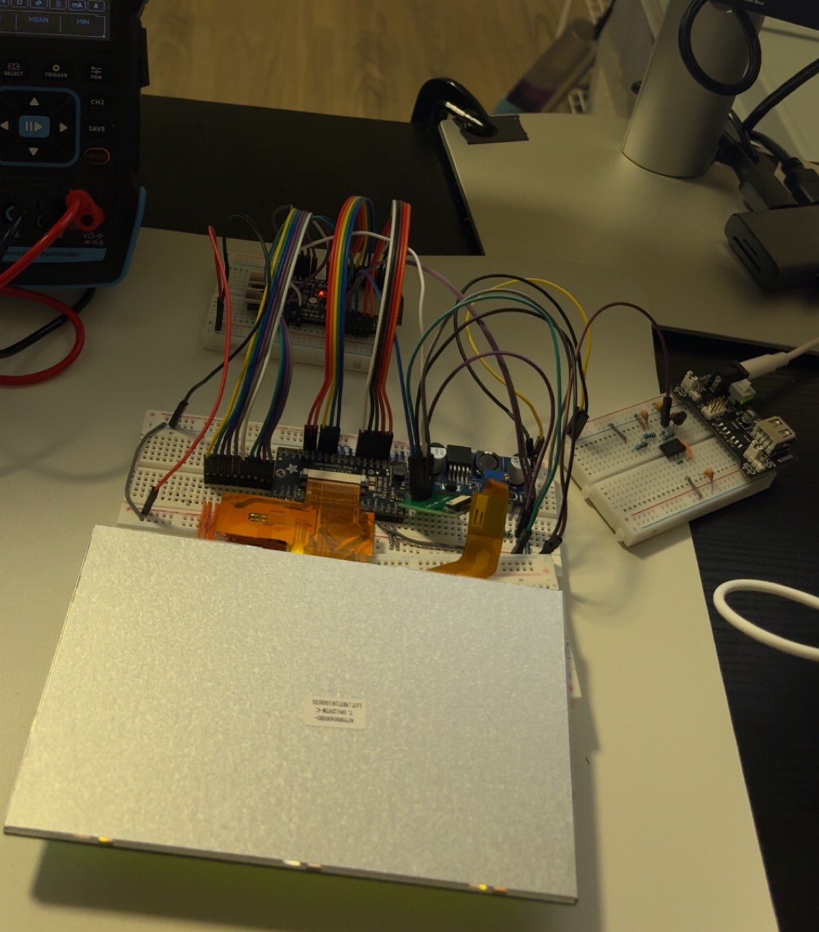
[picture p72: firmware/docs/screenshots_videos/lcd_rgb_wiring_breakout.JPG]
RGB bus wiring into the breakout


[Video: test patterns cycling](screenshots_videos/lcd_test_patterns_running.MP4)

Touch controller answers. A throwaway I2C scan on board 2 found the
GT911 at 0x14 (it picks 0x14 or 0x5D from the INT level at reset, which
the scan left floating), and a short poll read its product ID back as
"911" and printed X/Y as I dragged a finger around. Test code reverted,
the real driver comes later and will drive INT to pin the address.

Generator next. The resistors arrived, so the R-2R ladder goes on board
3 tonight. Changed the ladder to use one value only: every 2R leg is a
single 10k and every R is two 10k in parallel (5k), 23 parts. The ratio
is what sets linearity, and same-value parts hold 2:1 by construction,
parallel pairs also sit in one pair of breadboard rows where series
pairs need a middle row each. Tolerance math for 1% parts gives about
0.5 LSB typical at the mid-scale carry, so I'll meter the 10ks and put
the closest ones at the D7/D6 end. Ladder output drops from 10k to 5k,
which moves the Sallen-Key filter from 23 kHz (Q 0.73) to 33 kHz
(Q 0.69) with R38 left at 10k. Still flat, just a slightly higher
corner.

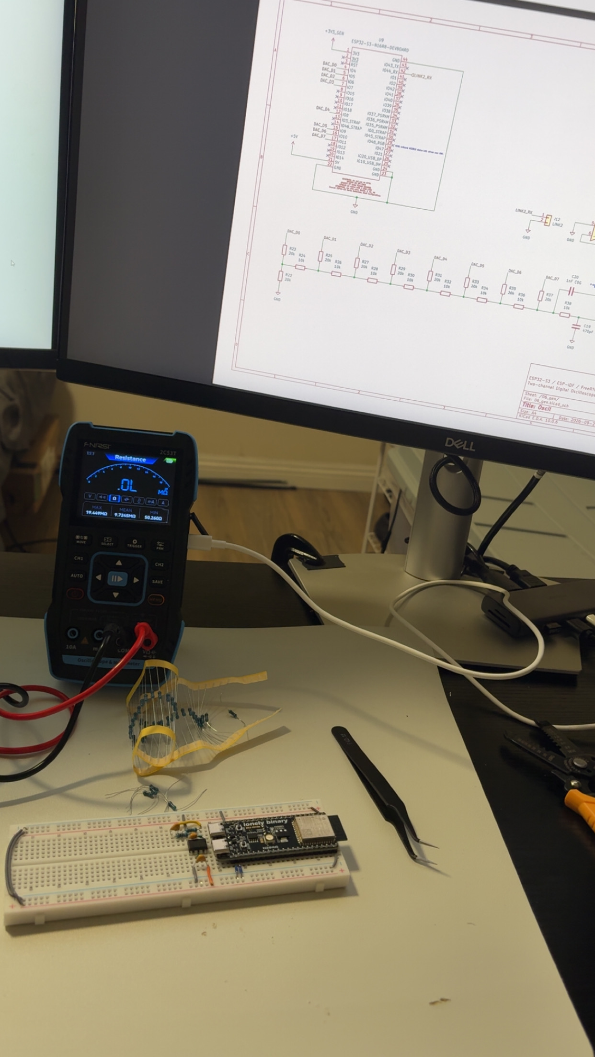
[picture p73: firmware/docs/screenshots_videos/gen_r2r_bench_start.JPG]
Bench set up for the ladder


## 2026-09-30

Ladder bit weights. Each bit set alone, measured at the ladder output
(the R38 row) against board 3's 3V3 pin, 3.288 V. Expected is
3.288 x code / 256. Meter zero offset of 0.7 mV subtracted.

| Code | Bit | Expected | Measured | Error |
|---|---|---|---|---|
| 0 | none | 0 | 0.7 mV | meter offset |
| 1 | D0 | 12.8 mV | 12.7 mV | -1% |
| 2 | D1 | 25.7 mV | 25.7 mV | 0% |
| 4 | D2 | 51.4 mV | 51.5 mV | +0.2% |
| 8 | D3 | 102.8 mV | 102.9 mV | +0.1% |
| 16 | D4 | 205.5 mV | 205.2 mV | -0.1% |
| 32 | D5 | 411.0 mV | 409.7 mV | -0.3% |
| 64 | D6 | 822.0 mV | 817.3 mV | -0.6% |
| 128 | D7 | 1.644 V | 1.651 V | +0.4% |
| 255 | all | 3.275 V | 3.271 V | -0.1% |

Every bit within 1% on 1% parts, with the all-10k ladder (2R single,
R as parallel pairs). The MSB is 0.4% high, about half an LSB at the
127 to 128 carry, so the output stays monotonic.

Two traps on the way. First reading at code 255 was 2.2 V, which was
the D0 node, not the output: with all bits high, the node next to the
terminator sits at 2/3 of the rail, and a quick nodal solve matched it
to the millivolt. Then the single bits read almost zero while 128 and
255 read the full rail, because I was probing the top of R37, which is
GPIO11 itself. The output is the bottom of R37, the row R38 starts in.

Also found board 3's 3V3 at 2.9 V on USB. Not the board: the USB hub
was also charging my phone and its 5 V sagged. Unplugged the phone and
the rail came back to 3.288 V.

Ladder built beside the generator sheet

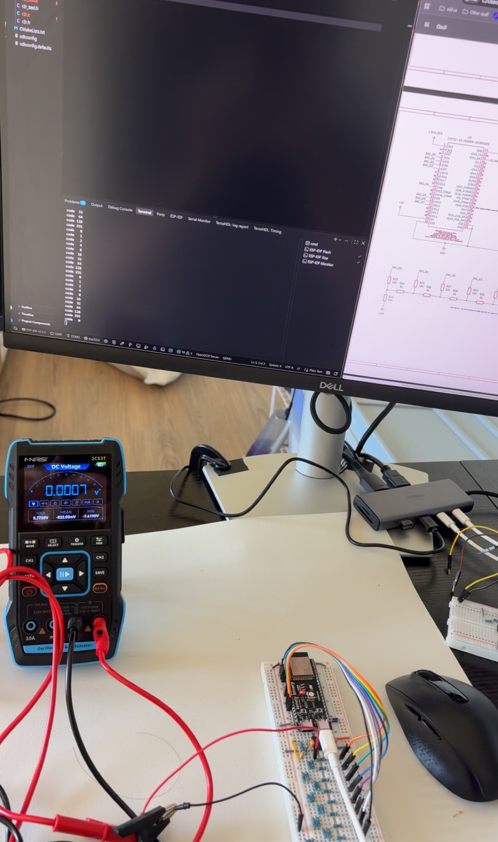
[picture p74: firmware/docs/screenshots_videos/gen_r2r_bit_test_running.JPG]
Bit test running, code 0 at the ladder output


Ladder staircase. Swapped the bit test for the ramp: codes 0 to 255,
20 us each, on repeat. On the scope at the ladder output it's a clean
sawtooth, 0 to 3.28 V by cursor, repeating every 5.44 ms. That's a bit
longer than the ideal 5.12 ms (256 x 20 us) because each code also pays
for the loop and the store, and every 64th ramp yields a tick to the
idle task, so about 21 us per code in practice. At 2 ms/div the 12.8 mV
steps are too fine to see, which is expected, the bit-weight table
above already puts the 127 to 128 step within half an LSB.

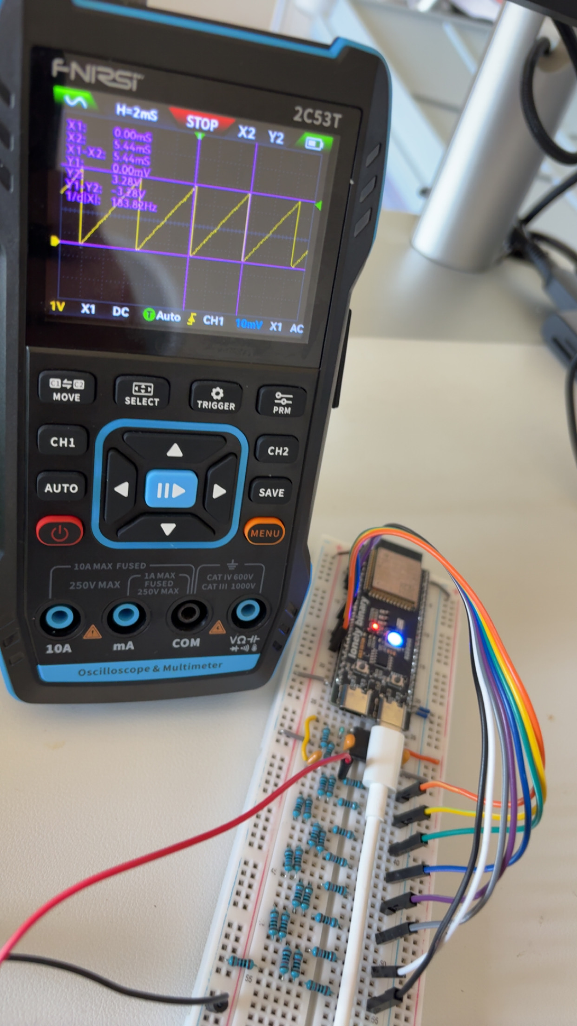
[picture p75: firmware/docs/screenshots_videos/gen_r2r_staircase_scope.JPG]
Staircase on the scope, cursors on one ramp


[Video: staircase running](screenshots_videos/gen_r2r_staircase_running.MP4)

Waveforms from a timer interrupt. A 32-bit phase accumulator adds a
tuning word every sample, and the top 8 bits pick the next code: from a
256-entry sine table, a compare for square, the index itself for saw,
folded for triangle. f_out = tw x 100 kHz / 2^32, so 1 kHz is
tw = 42,949,673 and the step is about 23 uHz. The math is pure C and
host-tested first: tuning word, 1234 Hz counted over 10 s to +-1 cycle,
10% duty, range limits, table landmarks. All seven host suites pass.

On the board it runs in a 100 kHz Timer Group 0 interrupt on core 1,
set up from the registers. The ISR acknowledges, re-arms, then does one
DDS step and one GPIO_OUT store. Everything it touches lives in IRAM or
RAM: the sine table isn't const (a const table lands in flash), and the
shape select is if/else, not a switch that GCC could turn into a jump
table in flash.

Checked at the ladder output: sine, square 50% and 10%, saw and
triangle at 1 kHz, sine at 100 Hz, 5, 10 and 20 kHz. At 10 kHz a sine
is only ten steps per cycle, which is the limit the filter has to work
with. ISR execution time on the timing pin not measured yet.

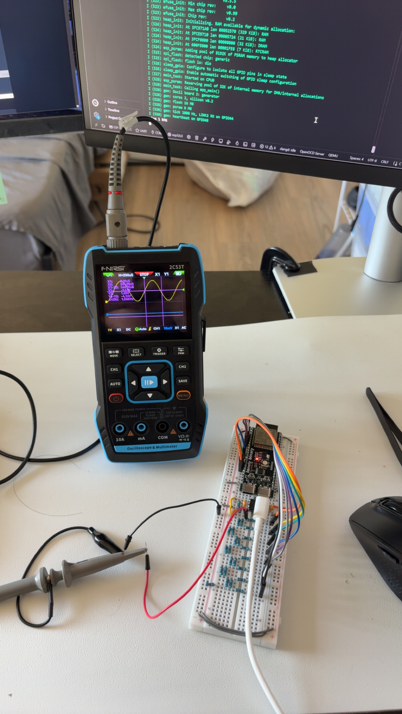
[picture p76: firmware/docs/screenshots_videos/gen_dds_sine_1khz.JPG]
Sine, 1 kHz, unfiltered


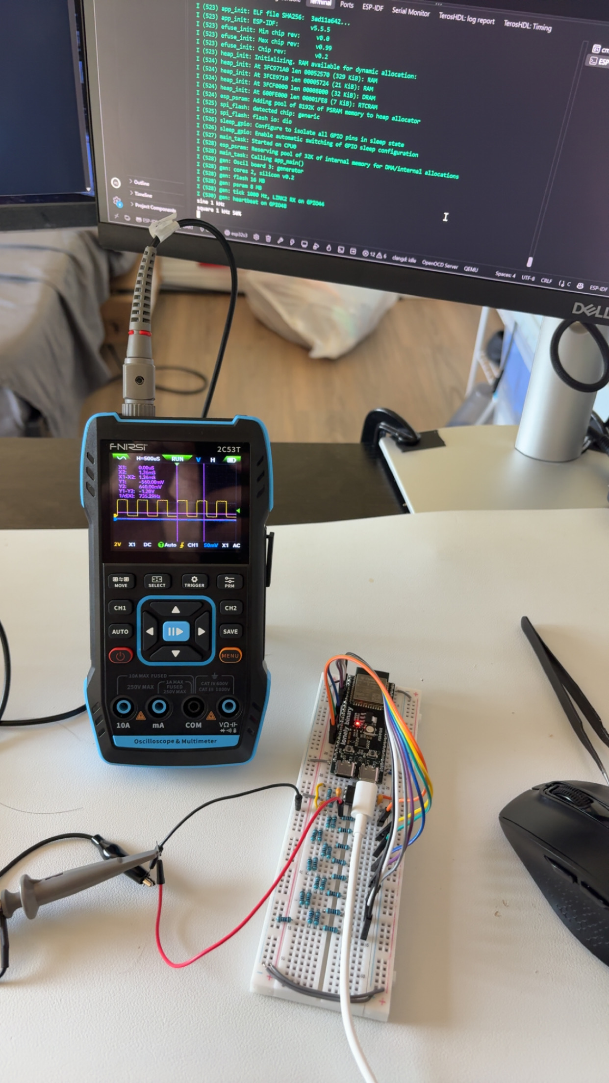
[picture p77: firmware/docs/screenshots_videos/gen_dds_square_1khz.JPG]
Square, 1 kHz


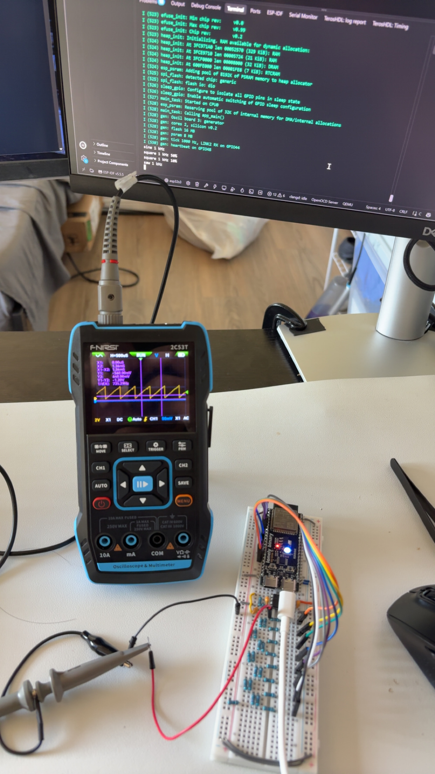
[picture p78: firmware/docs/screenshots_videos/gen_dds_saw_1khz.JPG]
Saw, 1 kHz


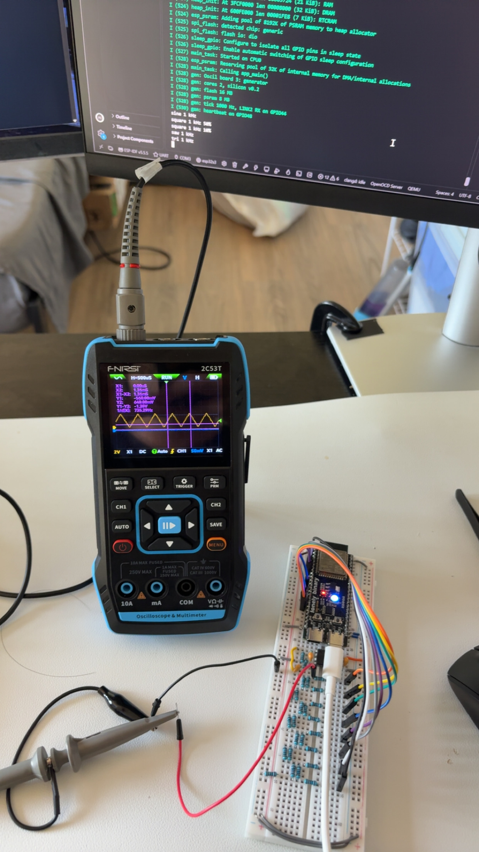
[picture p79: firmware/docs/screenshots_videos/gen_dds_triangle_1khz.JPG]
Triangle, 1 kHz


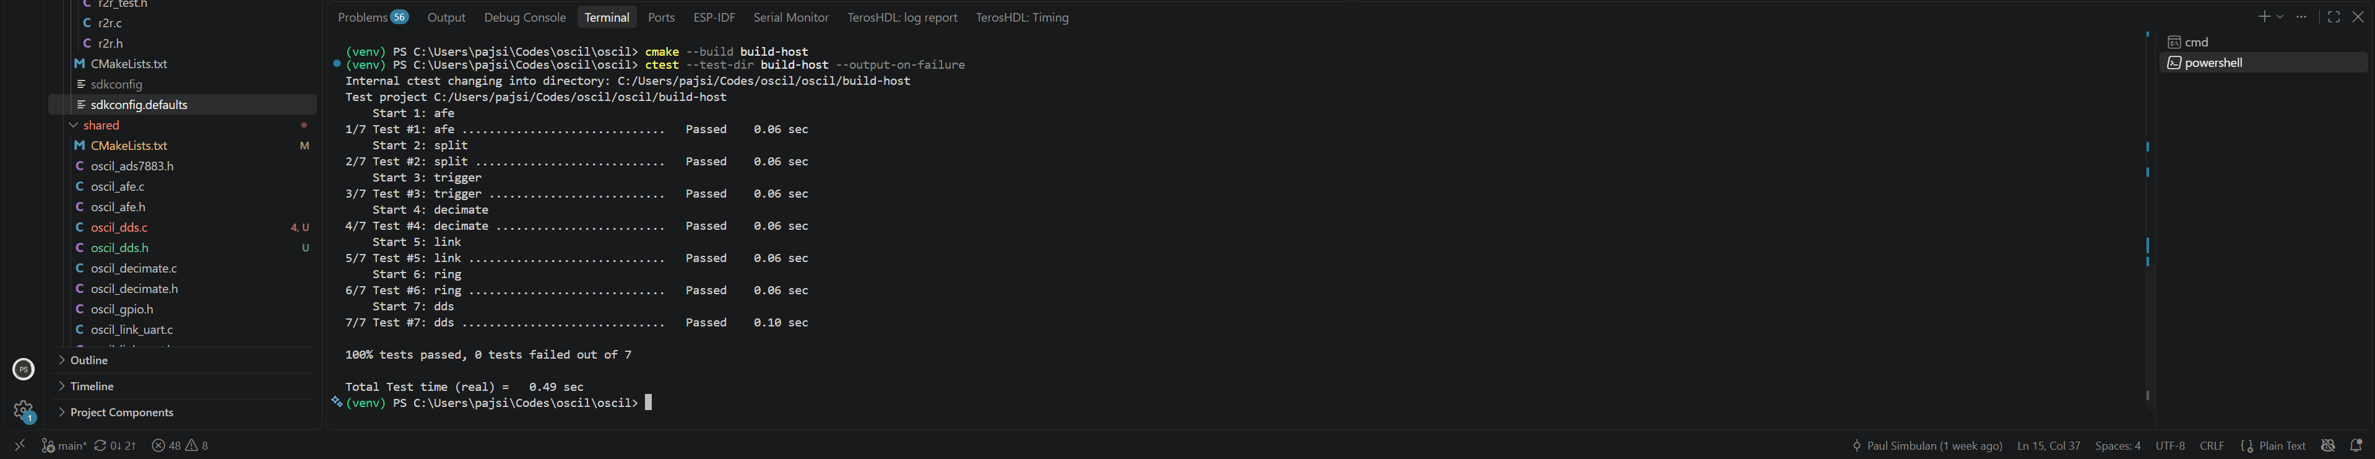
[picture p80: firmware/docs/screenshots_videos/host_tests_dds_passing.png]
Seven host test suites passing, DDS added


LVGL on the panel. The display now draws through LVGL 9.3 and
esp_lvgl_port instead of filling the framebuffer by hand. Two PSRAM
framebuffers with tearing avoidance (LVGL draws one while the panel shows
the other), and 10-line bounce buffers in internal RAM so the LCD DMA
never waits on PSRAM. LVGL renders on core 1, the RGB refill interrupt
stays on core 0. First screen is plain: the default light theme, "Oscil"
centred, and LVGL's FPS/CPU monitor in the corner. Held still for a
minute with no drift or tearing.

Two snags. The build failed first: the manual pinned LVGL 9.2 but the
newest esp_lvgl_port 2.x uses a colour format added in 9.3, so the
manifest now allows LVGL 9.3. Then the grey text and the monitor box came
out purple. The bit-line test showed why: black was maroon, and the last
band (R7 alone) matched the background, so R7 was stuck high. The
jumpers on that side of board 2 had shifted two rows, putting R5 and
below on the wrong header pins, one of them 3V3. Moved them back and
black is black again.

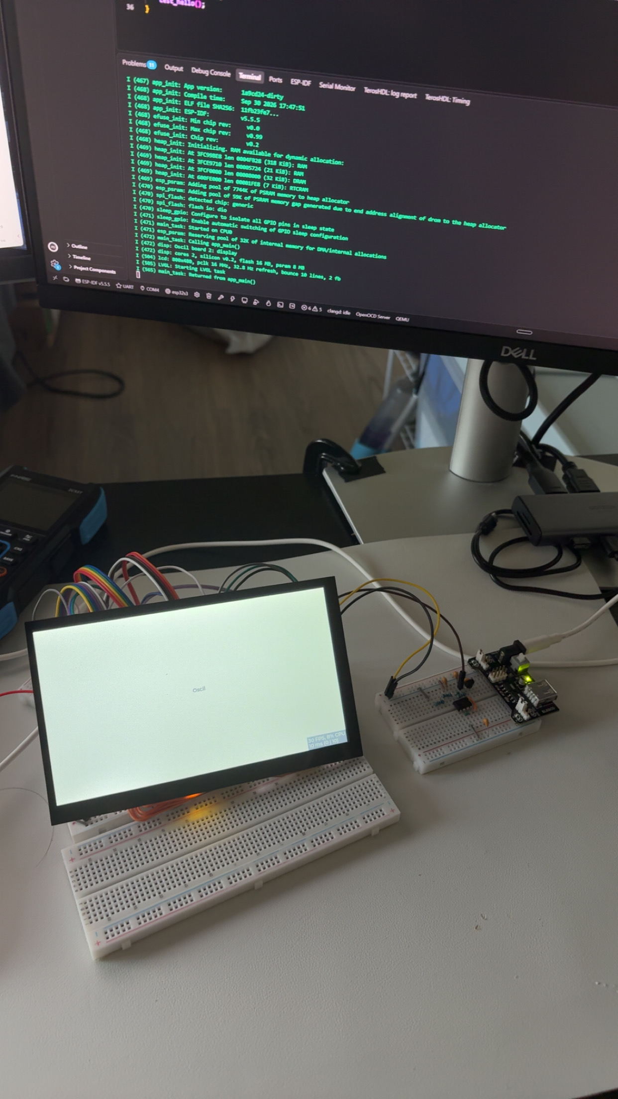
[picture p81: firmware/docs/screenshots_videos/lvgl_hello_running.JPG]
LVGL hello screen


RGB bus wiring, panel flipped

[Video: LVGL hello screen running](screenshots_videos/lvgl_hello_running.MP4)

Touch. The GT911 now runs through Espressif's esp_lcd_touch driver and
feeds LVGL as an input device. At reset the driver holds INT low, which
makes the chip answer at 0x5D instead of the 0x14 the earlier throwaway
scan found, the boot scan sees exactly one device at 0x5D and reads the
product ID back as "911". A red dot follows the finger and every press
prints its coordinates. X and Y come out in the right directions, no
mirroring or swap needed.

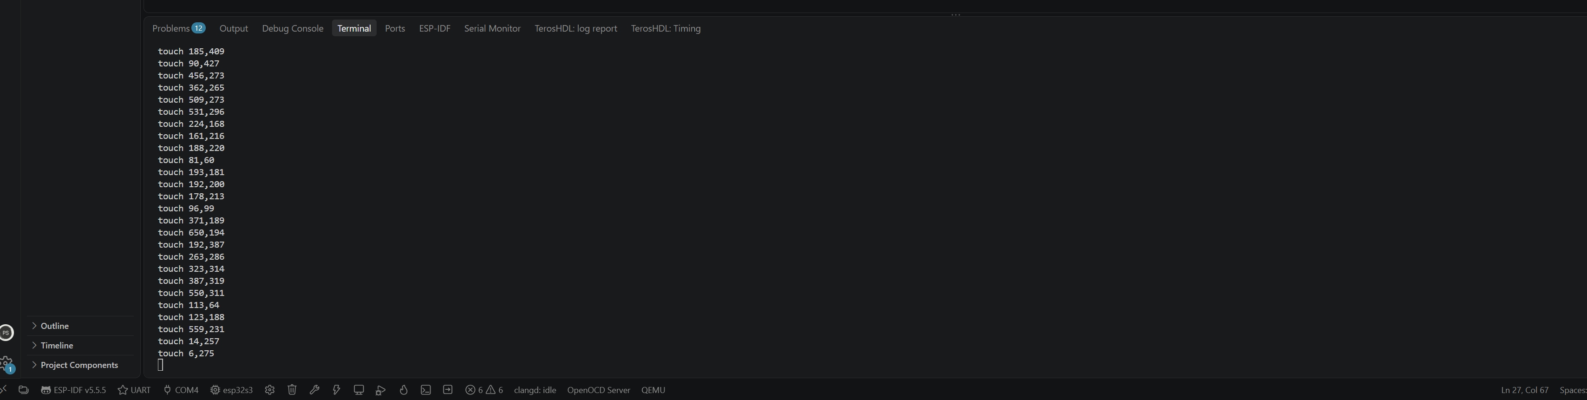
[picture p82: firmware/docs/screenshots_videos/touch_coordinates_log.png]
Touch coordinates in the monitor


[Video: dot following the finger](screenshots_videos/touch_dot_following_finger.MP4)

Scope view, first try (not working yet). Board 2's links moved into their
own module, and a scope view draws the min/max frames from board 1 onto
an 800x400 plot: a graticule drawn once and copied each frame, one
vertical run per column from min to max, CH1 yellow and CH2 cyan, and
two frame slots between the link task and the renderer so a slow draw
drops old frames instead of tearing. Screen comes up with the plot and
the grid, but no trace.

The LINK line says why: about 1 frame/s gets through instead of the 30
board 1 sends, and the CRC, COBS and length counters climb fast. FIFO
overflows, ring drops and framing errors all stay at 0, so board 2 keeps
up and the baud matches, the bytes are arriving with bits flipped. Since
the board 1 to 2 test passed at 31.8 frames/s before the
display was running, this points at the wiring rather than the code:
the 16 MHz pixel clock and 16 data lines now switch next to the link
wires, and the grounds run through long breadboard jumpers.

Along the way the bench 5 V sagged to 4.1 V under load. The backlight
boost draws about 260 mA, and the breadboard module makes 5 V from 9 V
with a small linear regulator that has to burn 4 V x 0.3 A, about
1.2 W. Moved the XL6009 to its own bench supply at 5.0 V, the module
now only feeds the front end and holds 5 V.

Next: short ground between boards 1 and 2 beside the link wires, link
wires routed away from the display bundle, and 1 Mbaud as a fallback.

What it should look like:

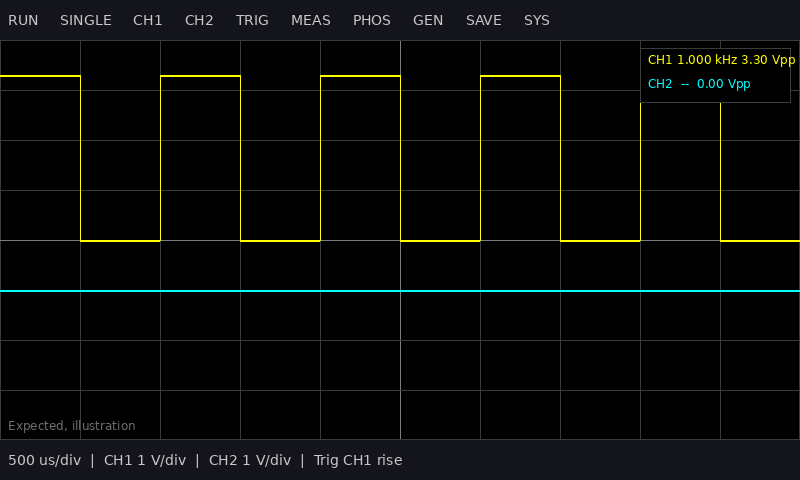
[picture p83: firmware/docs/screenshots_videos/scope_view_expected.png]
Expected scope view (illustration)


What it does today:

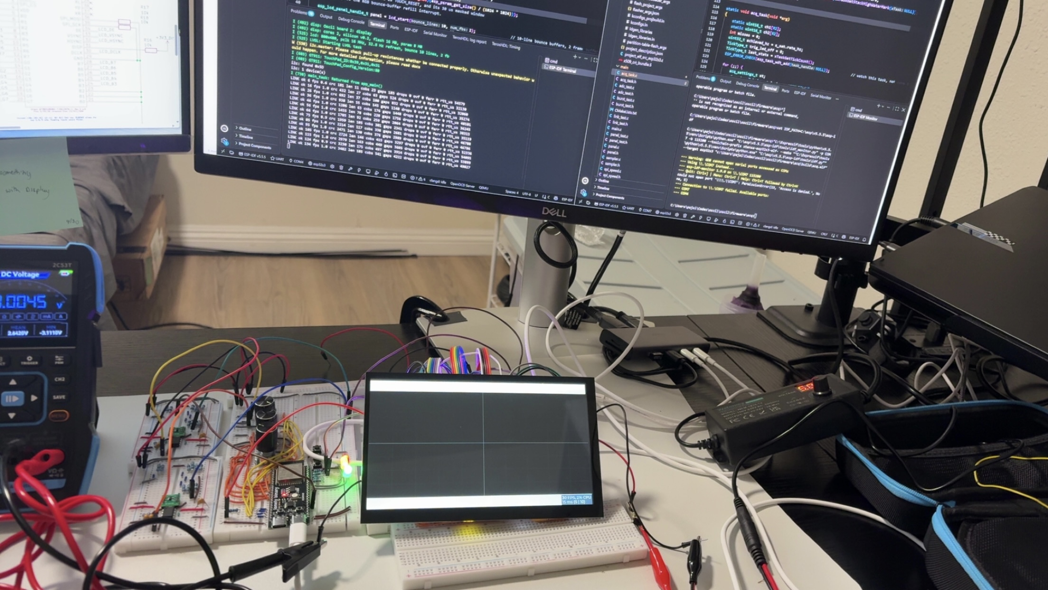
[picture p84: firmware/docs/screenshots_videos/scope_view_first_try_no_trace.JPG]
Scope view, grid only, link corrupting frames


[Video: scope view first try](screenshots_videos/scope_view_first_try.MOV)

## 2026-10-01

Scope view, live. Board 1's frames now draw on board 2's screen: the
1 kHz test square on CH1 over the graticule, the link at 31.8 frames/s
with zero errors. Getting there took a day of isolation tests, because
the failure only showed up with everything running.

The symptom: about 1 good message per second, CRC, length and COBS
errors climbing, a grid with no trace. Each piece was added back alone,
one flash per test: link only, then the panel, LVGL, touch, and the
scope view with no frames fed to it. All clean at 31.8/s. Connecting the
frame callback broke it again, and leaving the drawing task asleep while
still receiving and copying frames made it clean. So the trigger was the
drawing, not the wiring.

Drawing alone exposed the real counter: ovf, the UART's hardware RX FIFO
overflowing. Each frame the scope task copies a 640 KB background in
PSRAM and redraws the traces, about 34 ms of heavy memory traffic, and
the UART interrupt on core 0 couldn't always empty the 128-byte FIFO in
time. Four changes fixed it:

- UART interrupt raised to level 3 so it runs ahead of the display's.
- RX FIFO threshold from 64 to 32 bytes: more headroom before overflow.
- On overflow, reset the RX FIFO instead of only counting it. Before
  this, one overflow left the receiver broken for good, now it costs a
  frame and the decoder resyncs on the next delimiter.
- A 10 ms pause after each draw, so core 1's idle task runs (the task
  watchdog was firing) and PSRAM gets a gap. ovf stayed at 0 after this.

Then a crash on re-enabling the measurement labels: LVGL's built-in
printf doesn't do %f, lost its place in the argument list and read a
float as a string pointer (NULL). Formatting with the C library's
snprintf first fixed it.

Where it stands: stable, 8 frames/s on screen with the full canvas
redraw (target 25+), and the trace is live but not clean yet, with
gaps in the highs. The captured data from board 1 was a clean 50% square
when dumped earlier, so the next look is board 2's drawing path, along
with only redrawing what changed to get the frame rate up.

Before the fix, link errors climbing while frames draw:

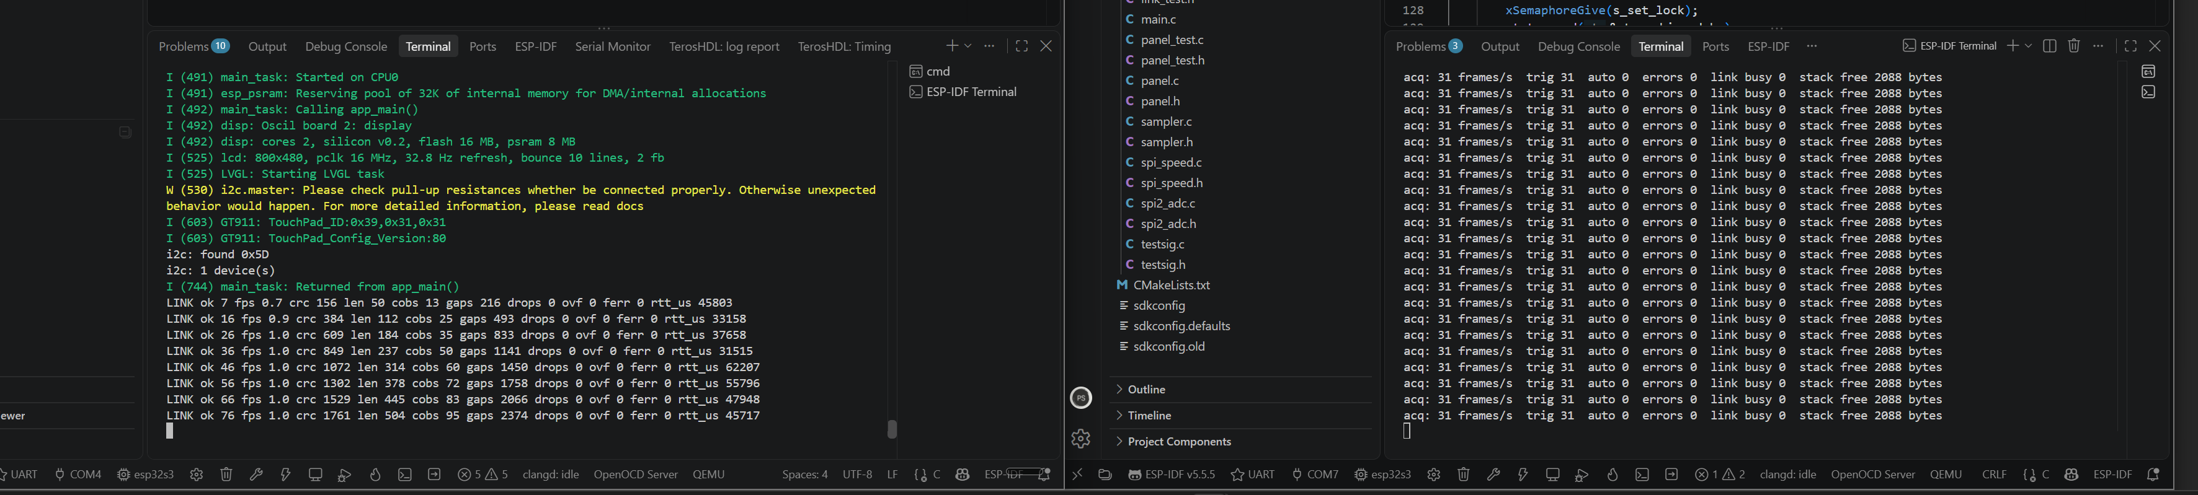
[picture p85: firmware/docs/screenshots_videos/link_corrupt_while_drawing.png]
LINK errors while drawing


After the fix, link clean at 31.8/s with the scope drawing:

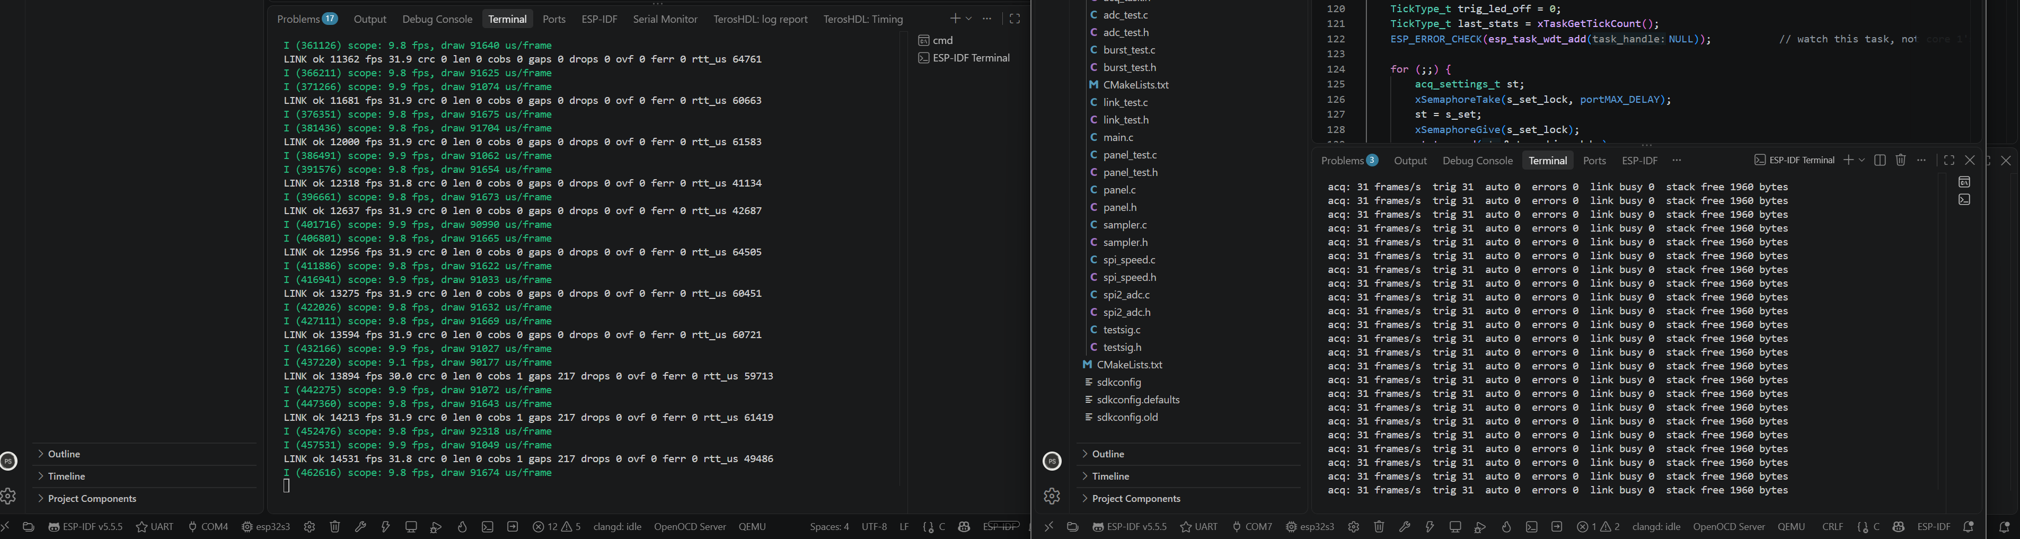
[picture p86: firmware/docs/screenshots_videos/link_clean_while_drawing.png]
LINK clean while drawing


First trace on screen, with the gaps in the highs:

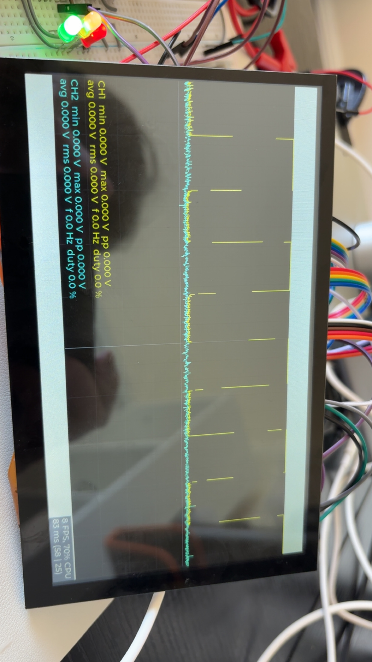
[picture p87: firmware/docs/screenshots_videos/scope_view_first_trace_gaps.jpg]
First live trace


The scope view running on the bench, board 1's 1 kHz square on CH1:

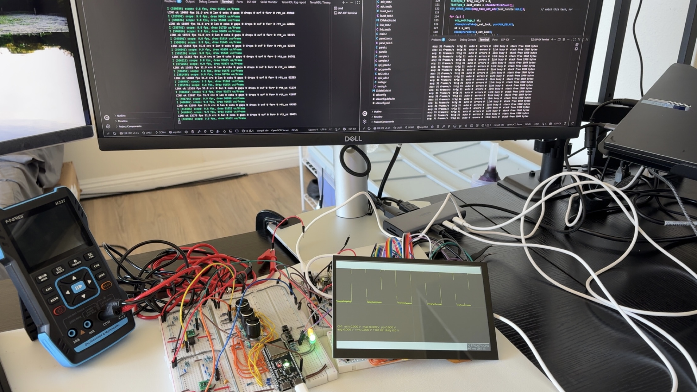
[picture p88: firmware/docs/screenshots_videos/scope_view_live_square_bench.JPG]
Live scope view on the bench


Measurements. Board 1 now measures each channel from the full
1600-sample record, before decimation, and sends the results in the
frame header: min, max, peak to peak, average, true RMS (DC included),
frequency and duty. Board 2 only displays them. Average and RMS come
from one pass with double accumulators, frequency reuses the trigger:
every rising crossing of the midpoint (10% hysteresis) across the
record, first to last with the sub-sample fractions, over the achieved
sample rate. Duty is the share of samples above the midpoint. Host
tested first: DC, sine RMS, a 1 kHz sine within 0.1%, a 25% square.
Eight host suites pass.

On the 1 kHz test square, nominal calibration:

| Measurement | Oscil | Expected |
|---|---|---|
| Frequency | 996.0 Hz | 1000 Hz |
| Duty | 50.0% | 50% |
| Average | 1.749 V | midway between the levels |
| RMS | 2.431 V | high level / sqrt(2) |
| Min / max | -0.235 / 3.590 V | levels about -0.13 / 3.45 V, plus noise |
| Peak to peak | 3.825 V | max - min |

The level offsets are the nominal calibration, the real one comes later.
The link stays at 31.8 frames/s with zero errors and board 1 still
captures 31 frames/s with the measuring added.

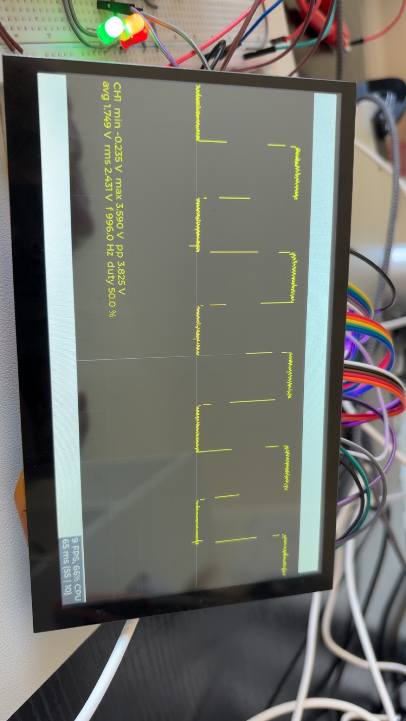
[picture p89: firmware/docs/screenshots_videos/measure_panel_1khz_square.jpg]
Measurement panel on the 1 kHz square


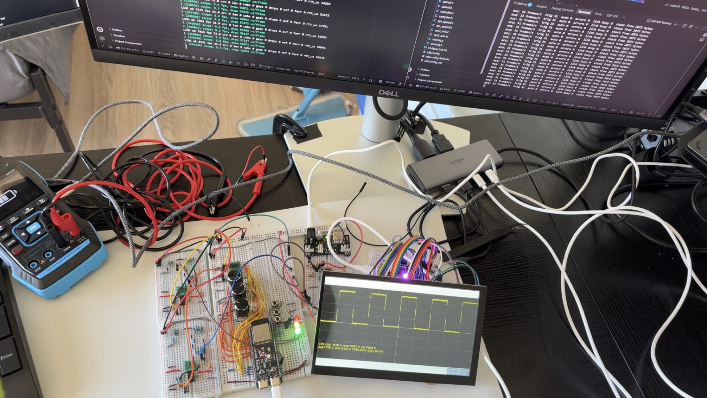
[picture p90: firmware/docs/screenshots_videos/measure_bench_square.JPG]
Bench with measurements running


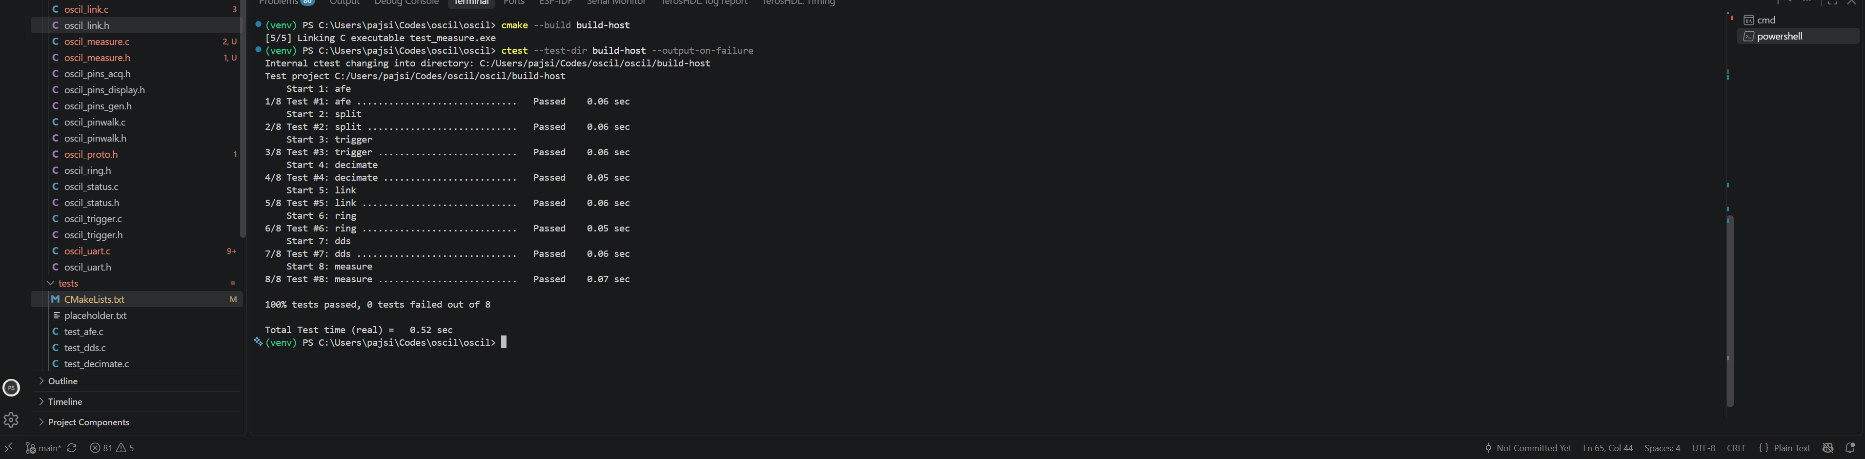
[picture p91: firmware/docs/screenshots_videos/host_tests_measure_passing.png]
Host tests, measurements added


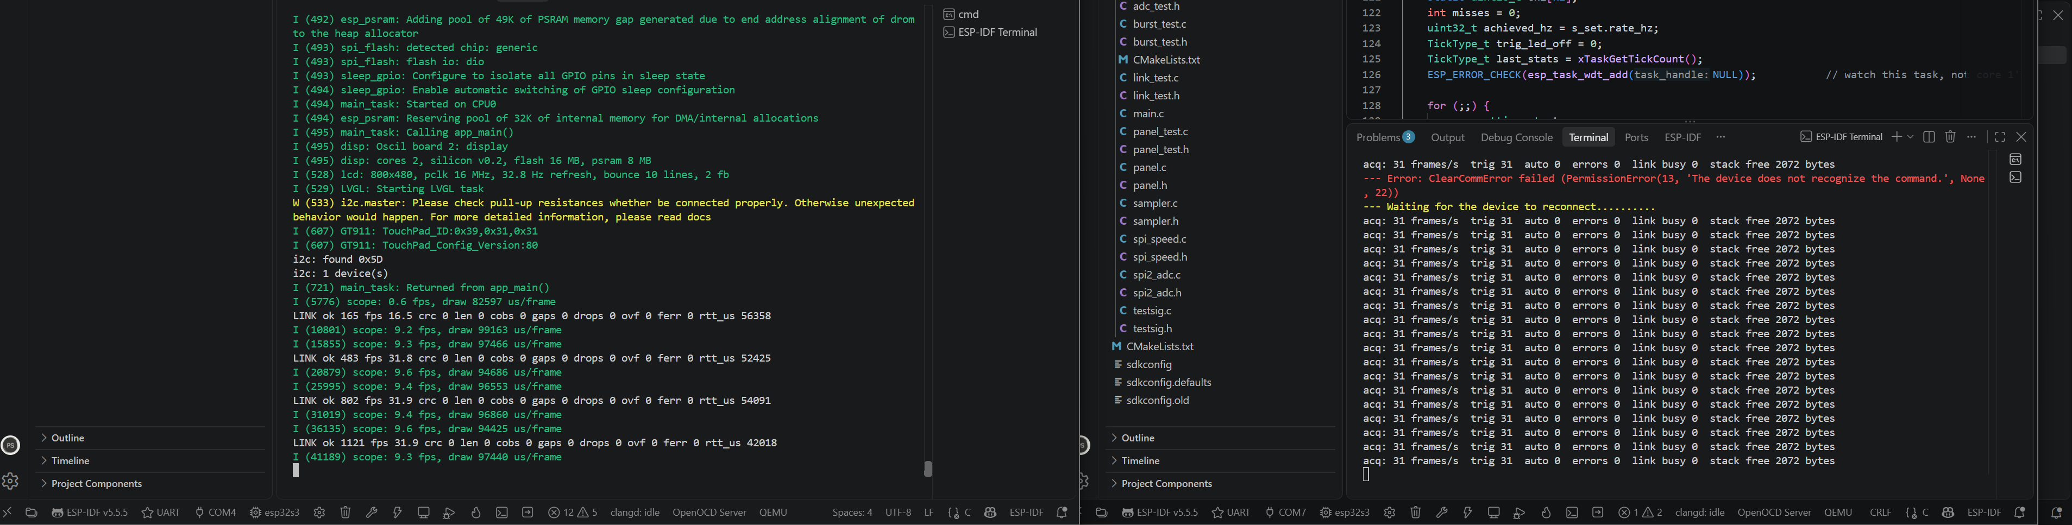
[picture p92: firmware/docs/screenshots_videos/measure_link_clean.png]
Link clean, board 1 measuring


[Video: measurements running](screenshots_videos/measure_running.MP4)

## 2026-10-02

Controls. Board 2 now owns every user setting in one struct, and every
input goes through one function: the knobs and buttons on board 1 arrive
as key messages, the touch buttons call it directly, and both change the
same settings. Board 1 only reports turns and presses, it no longer
toggles RUN or SINGLE itself (a compile-time switch keeps that for
running board 1 alone), so a press can't toggle twice. Changes go out
only to the board that needs them: timebase and trigger to board 1,
V/div and channel on/off stay on the display. At startup board 2 pushes
its settings to board 1, so after a display reset both agree. Keys from
the link task reach the UI through a queue, so the link never waits on
the display lock.

Knob map: ENC1 timebase, ENC2 V/div of the selected channel (push swaps
channel), ENC3 trigger level (push flips the edge). Top bar: RUN/STOP,
SINGLE, CH1, CH2, TRIG, MEAS, PHOS, GEN, SAVE. The status bar shows
timebase, both channels' V/div, and the trigger source, edge, level and
mode.

Two problems on the way:

- Boot loop: the status bar was formatted with LVGL's own printf, which
  has no float support. The trigger voltage shifted the arguments and the
  last string pointer was garbage. Formatted with libc snprintf instead,
  the same fix as the measurement labels.
- In STOP the trace ignored V/div, because the canvas only redrew when a
  new frame arrived. A view change now redraws the last frame. Timebase
  and trigger still apply on the next capture: board 1 sends decimated
  columns, so a stopped trace can be rescaled vertically but not in time.

In STOP the link drops to the ping and state messages (0.9 messages/s)
and comes back to 31.8 frames/s with zero errors on RUN.

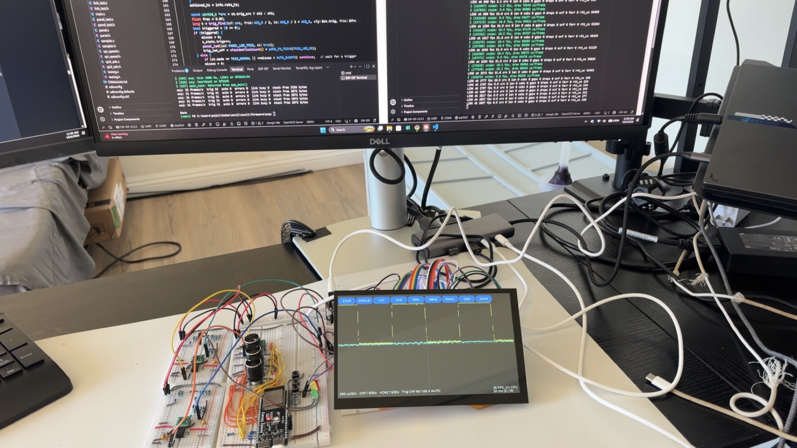
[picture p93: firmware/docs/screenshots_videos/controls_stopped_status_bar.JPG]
Stopped, status bar showing the settings


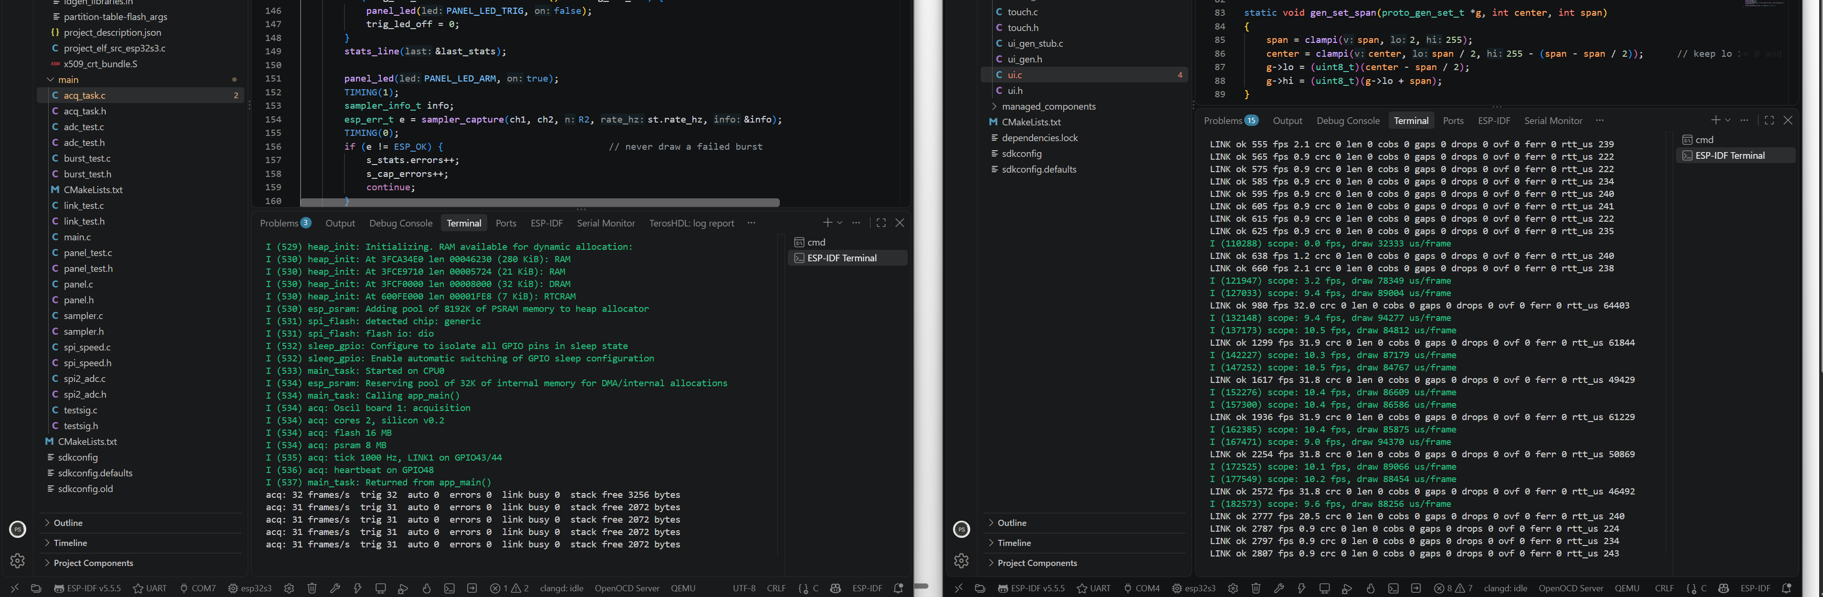
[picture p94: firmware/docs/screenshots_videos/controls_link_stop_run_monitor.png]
Link in STOP and RUN, board 1 still capturing on demand


[Video: knobs and touch driving the scope](screenshots_videos/controls_knobs_and_touch.MOV)

Generator screen. A second LVGL screen for the generator: shape buttons,
frequency (tap for a numeric keypad), amplitude and offset sliders, a
duty slider shown only for square, output on/off, and a one-period
preview. Every widget calls the same action function as the knobs, and
that function refreshes the screen after every generator change, so
touch and knobs follow each other both ways without loops (LVGL setters
send no events). Amplitude and offset are the DDS's own lo/hi codes,
clamped so neither leaves 0..255. The preview is drawn by dds_next(), the
same code board 3 runs in its timer interrupt, so the picture can't
disagree with the output. Board 2 sends the settings on LINK2 every
500 ms, board 3 starts following once its receiver is in.

Generator screen, 250 Hz sine with the preview

LINK2. Board 3 now listens. LINK2 is one-way, so board 3 can't
acknowledge anything, instead board 2 sends the whole generator state
right after every change and again every 500 ms, and board 3 applies
whatever arrives. A lost frame is corrected within half a second, and
receiving the same state twice changes nothing. Board 3 flashes its LED
white per frame, then green for output on or dim red for off, and logs
each change plus a status line every 5 s (frames received, time since
the last one, or a warning if the link goes quiet). Frames arrive about
every 500 ms with no gaps.

The generator screen also got easier to read: frequency is a button
that opens the keypad, each slider shows its value (Vpp, V, %), the
switch is labelled, and an output card at the bottom summarises the
setting ("1 kHz Sine, 0.00 to 3.30 V, output on"). All float text goes
through snprintf.

Three boards: generator screen, board 3 following

Board 3 log: frames every 500 ms, the applied setting

Settings and calibration. Board 2 now saves its settings (timebase,
V/div, trigger, channels, generator) to NVS two seconds after the last
change, with a version number and a CRC, and restores them at boot. A
burst of knob turns is one flash write, not dozens.

Board 1 has a two-point calibration per channel, stored in its own NVS
and sent to board 2 at boot. The procedure: input to GND (zero), then
input to the 3.3 V analog rail measured with a DMM (span), averaging
4096 samples each. The inputs are the top of the 750k divider resistors,
the same node the BNC centre goes to.

| Channel | Zero (codes) | Span (codes) | Gain | Offset |
|---|---|---|---|---|
| CH1 | 2067.2 | 3092.9 | 3.9442 | 1.6725 V |
| CH2 | 2074.0 | 3098.6 | 3.9481 | 1.6781 V |

Span source 3.273 V. Nominal was gain 4.0 and offset 1.65 V, about 1.4 %
and 25 mV off, which is what had the step 36 levels reading wrong. After
calibration the 1 kHz test square reads min -0.106 V, max 3.526 V,
avg 1.735 V, 996.0 Hz, 50.0 % duty (min/max include the trace noise).

It took four runs. The first ran with the sampler still active, so two
tasks drove the ADC bus at once. The second used a span value taken while
the analog rail was sagging. The third had CH2 reading the same code
(about 2763, the 2.2 V reference level) whatever the input: the jumper
wasn't in the R7 row, so the divider input was floating. The fourth was
clean, and the two channels agree within 0.1 %.

Spikes after rewiring. For a while both channels showed single samples
jumping to the edge of the screen. Every bad sample was off by exactly
2048 codes, the ADC's most significant bit, so it was a bit error on the
SPI read, not analog noise. Slowing SCLK from 26.67 to 20 MHz made it
worse (the sampler's timing is built around 26.67 MHz) and was reverted.
The spikes then stopped with the original code after the jumpers were
re-seated, so the cause was a marginal connection. If they come back:
press on the SCLK, CS and SDO jumpers while watching, and the CS setup
time (one clock now) is the first margin to add.

Calibration on the bench: DMM on the span source

Calibration results on the monitor

1 kHz square after calibration

Small display changes. Minor ticks on the scope's centre axes, five per
division, so a level can be read to a fifth of a division. A faint 4 x 4
grid in the generator preview, so amplitude and offset show where the
wave sits in the 0 to 3.3 V range. The generator output now always
starts off at power-up, whatever was saved, shape, frequency, amplitude
and offset are still restored.

Scope with minor ticks, calibrated 1 kHz square

Generator preview with its grid

Partition table. All three boards now use the same 16 MB layout:

| Partition | Offset | Size |
|---|---|---|
| nvs | 0x9000 | 24 KB |
| otadata | 0xF000 | 8 KB |
| phy_init | 0x11000 | 4 KB |
| ota_0 | 0x20000 | 4 MB |
| ota_1 | 0x420000 | 4 MB |
| storage (LittleFS) | 0x820000 | 7.9 MB |

Two app slots so an update can be written to the slot that isn't running
and rolled back if it fails, app rollback is on in the bootloader. NVS
kept its offset and size, so board 2's settings and board 1's
calibration survived. The images are far below a slot: board 1 about
241 KB, board 2 about 654 KB, board 3 about 213 KB.

The first build ignored the new settings: sdkconfig.defaults is only read
when no sdkconfig exists, and each board already had one. Set the custom
table and rollback in menuconfig on each board, and kept the lines in
sdkconfig.defaults so a fresh clone builds the same way.

All three boards building with the 16 MB table

## 2026-10-03

Board 2 joins Wi-Fi as a station. Everything is event-driven: the
driver reports start, disconnect and got-IP as events, and other tasks
wait on one event-group bit (online) instead of polling. A dropped
connection retries with exponential backoff, 1, 2, 4, 8, 16, 32 s up to
60 s, from a one-shot FreeRTOS timer, so a rebooting router isn't
hammered. SNTP starts once on the first IP so captures get real times.
Credentials are compiled in from a git-ignored secrets.h, provisioning on
the device is future work.

The ESP32-S3 radio is 2.4 GHz only and the home network is 5 GHz, so it
runs on a phone hotspot with its 2.4 GHz compatibility mode on. First
attempts showed the backoff working but never connecting, on the hotspot
it joined on channel 6, WPA2, RSSI -39 dBm, and got 172.20.10.6 by DHCP.
The scope and LINK1 kept running throughout: 31.8 frames/s, no errors.

Backoff while the network is unavailable

Connected to the hotspot

OTA. Board 2 now updates from SYS, using the display binary on the
latest GitHub Release. HTTPS checks the server certificate against
ESP-IDF's bundled roots, writes the other app slot, verifies the image
and sets it for the next boot. SYS shows the firmware version, Wi-Fi
state and RSSI, free and minimum heap, and the scope frame rate.

The first attempts reset while writing flash with the display running.
One watchdog reset stopped in the panic handler, later runs caught
illegal instruction and instruction-fetch errors. Pausing the scope
task, then holding the LVGL lock for the download, did not make it
reliable. The lock also held up UI callbacks from the link receiver,
so incoming bytes were dropped. An update with the LCD left unstarted
completed. That narrowed the problem to the display setup alongside
OTA, but did not identify the exact cause. The panic handler is now in
IRAM so failures during flash operations can be reported.

The update button now saves a one-time request in NVS and reboots.
Before starting the LCD, touch or LVGL, the next boot consumes the
request and starts an OTA task. It waits up to 30 s for Wi-Fi, downloads
with the screen disabled, then reboots. LINK1 keeps draining frames
without UI callbacks. A failed attempt returns to normal startup, the
request is already cleared, so another reset cannot start an update
loop.

Tested from 0.8.0 to 0.8.1, starting with the touchscreen button. The
download took about 26 s after entering update mode, the new image
booted from ota_1 at 0x420000, and the self-test confirmed it. The test
checks the LCD, touch and a recent frame from board 1, allowing up to
5 s for that frame. The screen returned and LINK1 stayed at about
31.8 frames/s with zero errors during the download and after reboot.

```text
ota: update requested, rebooting without LCD
ota: update mode: LCD, touch and UI disabled
ota: done, rebooting
App version: 0.8.1
ota: 0.8.1 is new: self-test
ota: new image confirmed
```

Update mode, certificate checks and the download starting

0.8.1 confirmed, scope running and LINK1 clean

[Video: touchscreen update from 0.8.0 to 0.8.1](screenshots_videos/ota_update_0_8_0_to_0_8_1.MP4)

Accounts on board 2. Added the Supabase HTTPS client and account session
code. Requests use the bundled certificate roots and the publishable key,
user requests carry the access token. The refresh token, username and user
id are saved in NVS. The access token stays in RAM and is renewed when
needed, including after reboot.

Tested sign-in as `paul_test`. TLS validated, sign-in returned ESP_OK and
the token was 800 characters. After a reset, the test printed "session from
NVS: paul_test" and obtained a token again without another password login.
Forced sign-out for the negative test, then supplied a wrong password.
It returned "Wrong username or password" with ESP_FAIL and no valid token.

LINK1 stayed at 31.8 frames/s in the sign-in run. The reset run recorded
one length error, 44 gaps and 281726 dropped bytes at startup, those counters
stayed flat in the following logs and reception returned to 31.8 frames/s.
The cause of that startup disturbance is not established. The scope drew
at about 4.7 fps, around 203 ms per frame, slower than the earlier run.

Device sign-in succeeded

Session restored after reset

Wrong password rejected, no token issued

Account screen. SYS now opens a page with Sign in, Create account and
Forgot password modes, a text keyboard, account status, Sign out and Back.
Password fields are masked. Create account asks for a secret phrase, reset
asks for that phrase and a new password. Network requests are queued to a
worker task so the LVGL task does not wait on HTTPS.

The manual's SYS replacement called the old OTA function. Kept the working
NVS request and reboot updater, so adding Account does not restore the
update path that failed with the LCD running.

The first touchscreen sign-in validated the certificate, then failed with
"esp-aes: Failed to allocate memory" and a TLS read error. The hardware AES
path needs temporary DMA-capable buffers, its allocation failed. Disabled
hardware AES in menuconfig and saved the same setting in sdkconfig.defaults.
TLS now uses software AES, with certificate checking still enabled. Account
operations worked after this change. Exhaustion versus fragmentation of
the DMA heap was not measured.

Recorded the three account screens, button navigation, password reset and
sign-in with the new password. Captures are kept with the firmware evidence,
the Supabase setup and PC isolation test stay under software.

Account sign-in screen

Create account screen

Forgot password screen

[Video: account screen buttons](screenshots_videos/account_screen_buttons.MP4)

[Video: account screen navigation](screenshots_videos/account_screen_navigation.MP4)

[Video: forgot password test](screenshots_videos/account_forgot_password_test.MP4)

[Video: password reset and sign-in with the new password](screenshots_videos/account_reset_new_password_sign_in.MP4)

Cloud photos. SAVE now takes a screenshot of the scope screen into RAM
and uploads it directly to the signed-in user's private Supabase folder.
The earlier file uploader expected a locally saved .osc capture, replaced
that path with an LVGL snapshot and BMP upload. No photo is written to
LittleFS. NVS keeps a screenshot counter across normal reboots.

The RGB565 snapshot is streamed as a 24-bit BMP, one converted row at a
time. An 800 x 480 image is 1,152,054 bytes. Raised the screenshots bucket
limit from 64 KB to 2 MB and saved the new limit in software/schema.sql.
The bucket remains private, with the existing owner policies.

Snapshot capture briefly takes the LVGL lock. The upload and metadata row
run on a worker task, a second SAVE while it is active reports "Photo
upload busy". Closing the request frees the snapshot. Signed-out SAVE is
refused. HTTP header and body read failures now return an error instead
of reporting a successful request.

The display rebuild compiled and linked, and the binary passed its app
partition size check with 65% free. Device testing passed: signed-out
SAVE showed "Sign in to save photos", repeated presses during uploading
showed "Photo upload busy", and a completed upload showed "Photo saved
to your account". Recorded the SAVE sequence and the resulting image in
Supabase.

The Account screen photo list and viewer are next. They are not part of
this change. The planned viewer will fetch only a selected photo into
RAM and free it when closed.

SAVE refused while signed out

Repeated SAVE presses while uploading

Photo saved to the signed-in account

[Video: cloud SAVE, busy guard and the Supabase image](screenshots_videos/cloud_photo_save_busy_supabase.MOV)

### Photo viewer and selected trace touch

Added My photos to the signed-in Account screen. The gallery lists 20
metadata rows per page, newest first, it does not download thumbnails.
Tapping a row fetches that photo with the user's access token. The BMP is
read a row at a time and converted into one RGB565 PSRAM buffer, at most
768 KB. Close frees it and returns to the list. Leaving while a request is
running cancels its result, so an old download cannot reopen a photo.
The bucket and owner policies are unchanged.

Kept the scope layout and changed the top buttons to a dark background,
with a yellow or cyan border around the selected channel. Holding near
that trace for 300 ms starts dragging. Vertical movement changes only
that channel's voltage offset, horizontal movement pans only its display.
It does not change the sample rate or acquisition trigger position. ENC1
press centres it again. ENC3 and TRIG use the selected channel as source.
The persisted settings structure has not changed, horizontal pan starts
at zero after reboot. SAVE is refused away from the scope screen.

The display compiled and linked. Seven host tests passed for BMP headers,
both row directions, padding, RGB565 colours and malformed input.

Photo viewer startup correction. The first device attempt reported
"Photo viewer unavailable" before opening the gallery. That message came
from queue or worker creation, before any Supabase request. The worker
asked for a 12 KB internal stack, moved it to PSRAM and made the queue and
task control blocks static so startup no longer needs that internal heap
allocation. Kept PSRAM XIP enabled because token renewal can write NVS.
Added startup heap diagnostics and a "worker ready" log.

## 2026-10-04

### Gallery review

Rechecked the PSRAM worker stack, static queue/task controls, token use,
private folder paths, image bounds and cleanup when leaving a request.
The nine host suites passed, including the seven BMP cases. Corrected an
offline pagination case: Next, Previous and Refresh now keep the current
page when no request can start. Made gallery JSON parsing strict and
added HTTP/stage logs for a failed list or photo download. Photo requests
use the same 2 KB HTTP buffers as the uploader.

The signed-out guard and RAM-only photo path remain in place. Trace pan
is limited to the selected channel, with bounded horizontal positions,
ENC1 resets both offsets and trigger controls use the selected source.
A saved STOP state can still boot to an empty grid because waveform data
is not persisted. RUN with AUTO is the first check in that situation.

### Photo viewer on the device

Opened a saved cloud photo in the device viewer. The new capture shows
"Photo 4" with the saved scope image, both channel traces, measurements
and the Close control. This confirms gallery startup and a selected photo
being displayed after the worker startup correction.

Saved cloud photo open on the device

### Touch failure during sign-in

The display rebooted after a GT911 I2C timeout. The backtrace reached
LVGL's fatal touch-read check, it did not show an Auth rejection.
Added a project-side adapter that releases touch on an error, logs the
failure and lets the next read retry. Reduced the touch bus to 100 kHz
for the breadboard harness. Downloaded components are unchanged.

Moved the account worker's 12 KB stack into PSRAM with the same XIP
requirement as the gallery. Queue and task creation are checked, failed
submissions clear Working and show an error. Added request start/finish
logs without passwords, phrases or tokens.

### Photo numbering after the board swap

The replacement display started at photo 1 while the account still held
photos from the old board. Before allocating a number, the uploader now
reads the account's highest shot_id and keeps the larger of that next
number and the local counter. Existing photos are never overwritten.

Storage errors now include the server response in the serial log.
Recognised duplicate-file responses retry with a fresh number, up to
three uploads per save, using the same RAM snapshot. Other errors stop
the save. No SQL or policy changes are needed.

## 2026-10-05

### CI

The display build on GitHub Actions had failed since Wi-Fi was added.
Five display sources include the git-ignored `secrets.h`, so a clean
checkout could not compile them. The workflow now copies
`secrets_example.h` to `secrets.h` for the display job only, so CI
builds with empty credentials and nothing real reaches GitHub. Moved
`actions/checkout` to v5 to clear the Node 20 deprecation warnings.

## 2026-10-06

### Version 0.9.0

The display had stayed at 0.8.1 since the OTA test, so everything added
after it, accounts, cloud photos, the gallery, trace dragging and the
touch and photo numbering fixes, still reported 0.8.1. Boards 1 and 3 had
no version set and showed a git describe string instead. All three
projects now set `PROJECT_VER` to 0.9.0, checked in each built image, and
the three images go out together as one release, `v0.9.0`. Board 2 takes
it over Wi-Fi, boards 1 and 3 are flashed over USB.

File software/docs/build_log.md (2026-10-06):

# Software build log

## 2026-10-03

Created `oscil-dev` in Supabase, in West US. Email sign-in is enabled,
confirmation is off. The device uses local account addresses that cannot
receive mail.

Applied `schema.sql` in the SQL editor. Supabase returned "Success. No rows
returned." The script creates `profiles`, `recovery` and `screenshots`, enables
row-level security, and creates a private screenshots bucket with a 64 KiB
file limit. Profile and screenshot policies restrict access to the signed-in
owner. Recovery has no client policies and its client grants are revoked.

The SQL is saved in the repo. The successful query confirms setup,
account and isolation checks were run separately below.

Supabase schema created

Deployed the `account` Edge Function from `index.ts`, with Verify JWT off.
The source uses Supabase's server-side service-role key to create the Auth
user, profile and recovery hash. The secret phrase is normalised and hashed
with PBKDF2-SHA256, a random salt and 100,000 iterations.

Tested signup from PowerShell with `paul_test`. The first request returned
`ok: True`. Repeating it returned HTTP 409 Conflict, rejecting the duplicate
username. Password reset, lockout and cross-account isolation were checked
with the two-user test below.

Account signup and duplicate rejection

Ran `tests/isolation_test.py` against `oscil-dev`. All 17 checks passed.
Both users could sign up and sign in. A uploaded a file and added its row,
B could not list or download it, write into A's folder, or insert a row as A.
The signed-out request returned no screenshots, and the recovery hash read
was refused. A could still read its own row.

Password reset refused the wrong phrase and accepted the right phrase with
different case and spacing. The old password stopped working, the new one
worked, and five wrong phrases locked further resets.

The PC's `python` command first resolved to MSYS2. Used Windows Python 3.13,
installed `requests` there, and set the Supabase URL and publishable key in
the PowerShell environment. The final run returned `ALL PASS`.

Supabase isolation tests passed

Raised the screenshots bucket limit from 64 KiB to 2 MB for the device's
800 x 480 BMP photos (1,152,054 bytes each). The change is saved in
`schema.sql`, the bucket stays private with the same owner policies.

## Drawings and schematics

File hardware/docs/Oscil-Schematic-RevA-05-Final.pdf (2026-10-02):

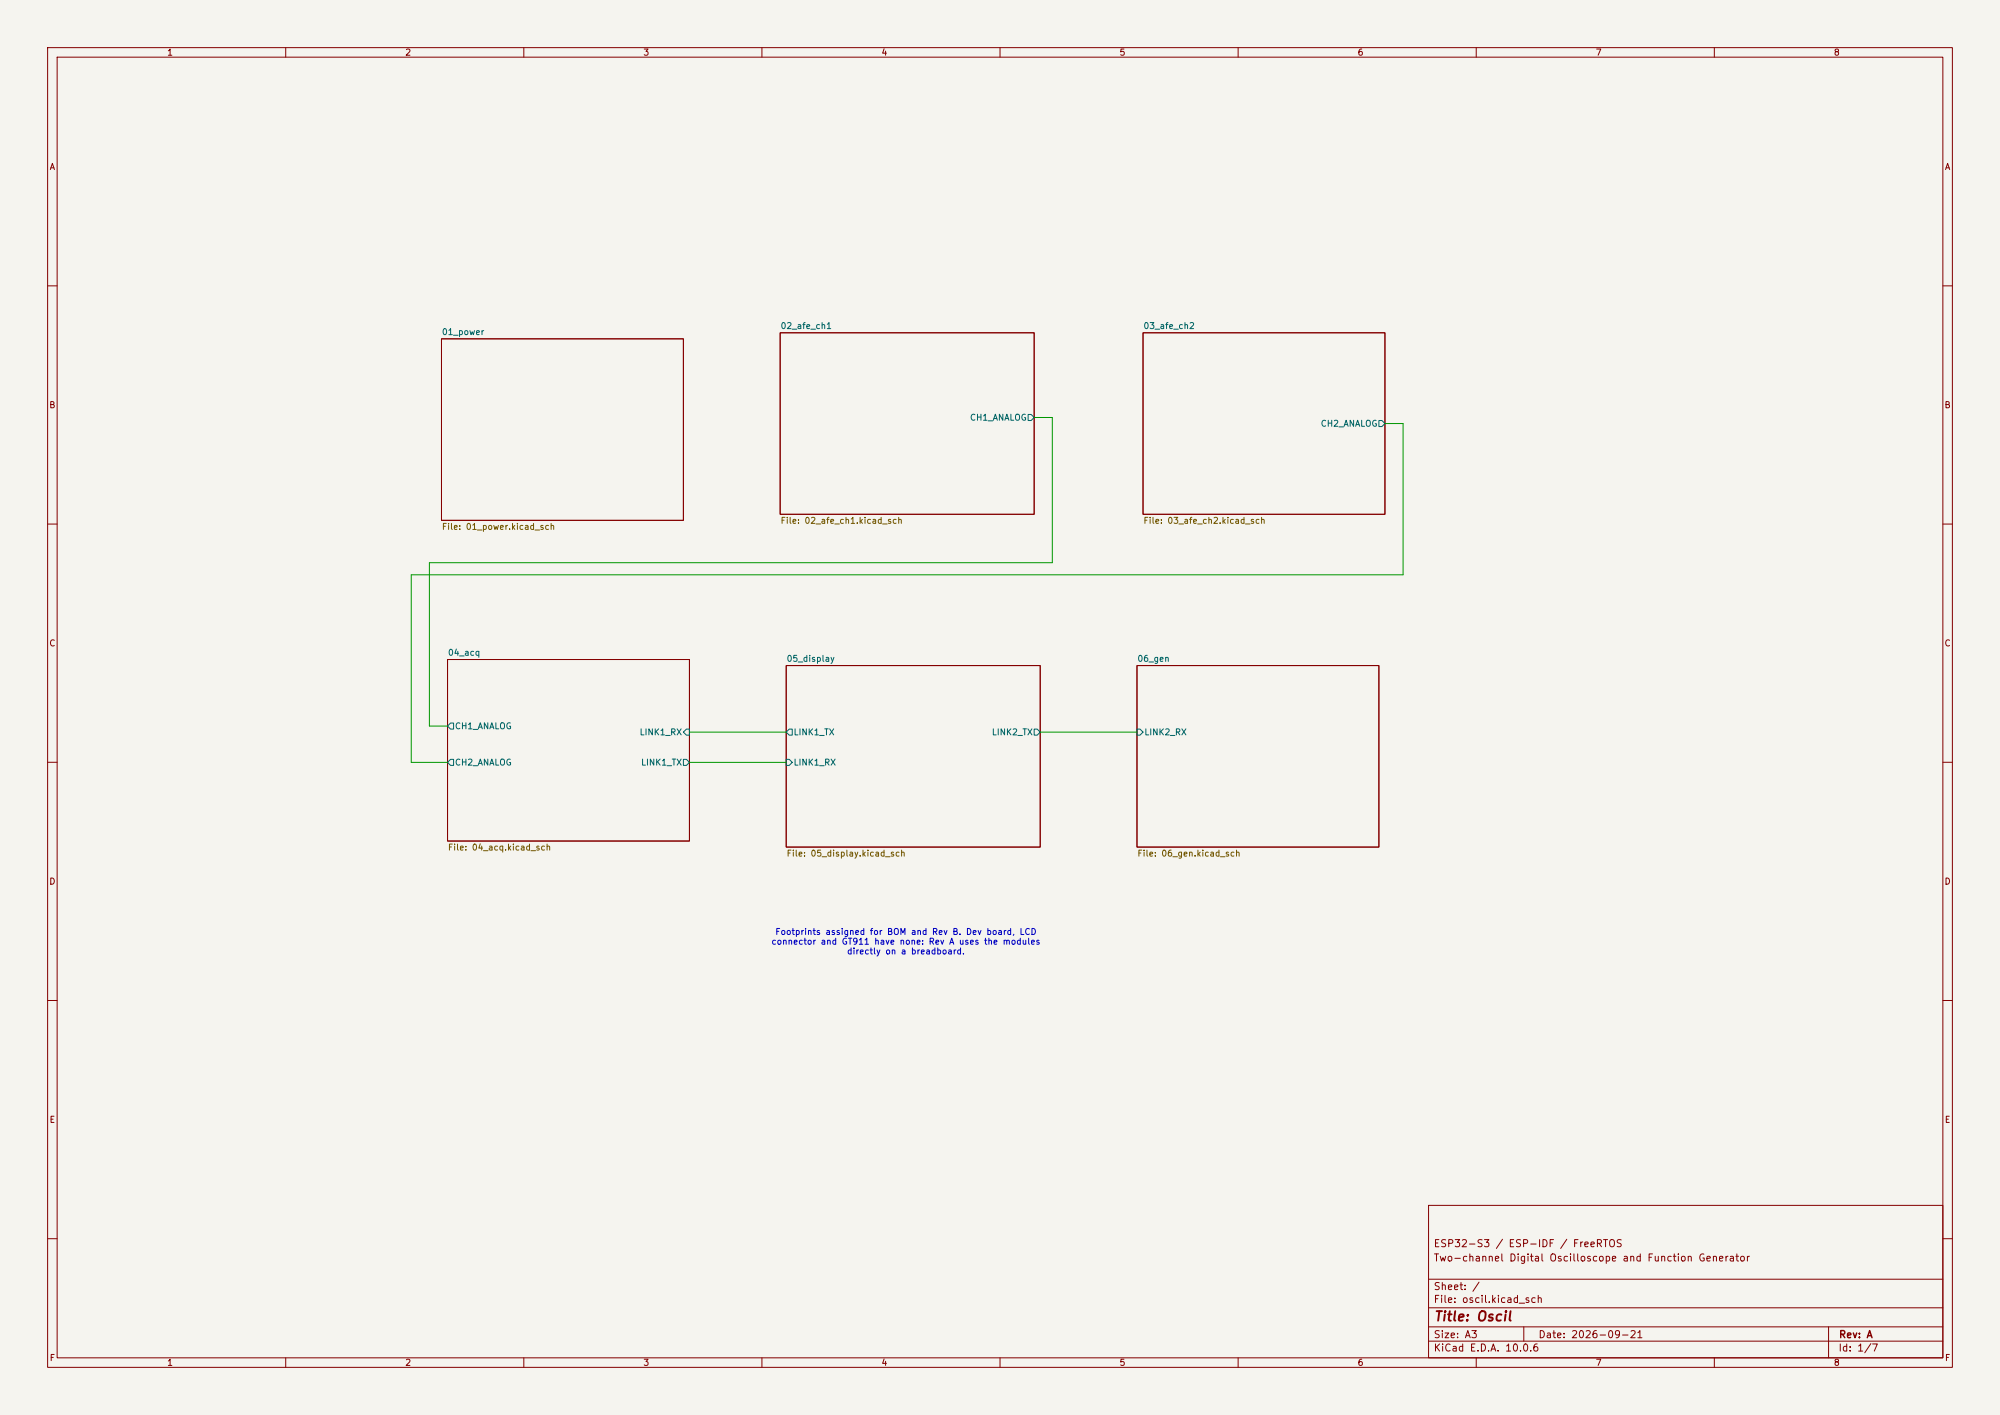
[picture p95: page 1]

Footprints assigned for BOM and Rev B. Dev board, LCD
connector and GT911 have none: Rev A uses the modules directly on a breadboard.

ESP32-S3 / ESP-IDF / FreeRTOS
Two-channel Digital Oscilloscope and Function Generator

Size: A3 | Rev: A | F Date: 2026-09-21
KiCad E.D.A. 10.0.6 | Id: 1/7

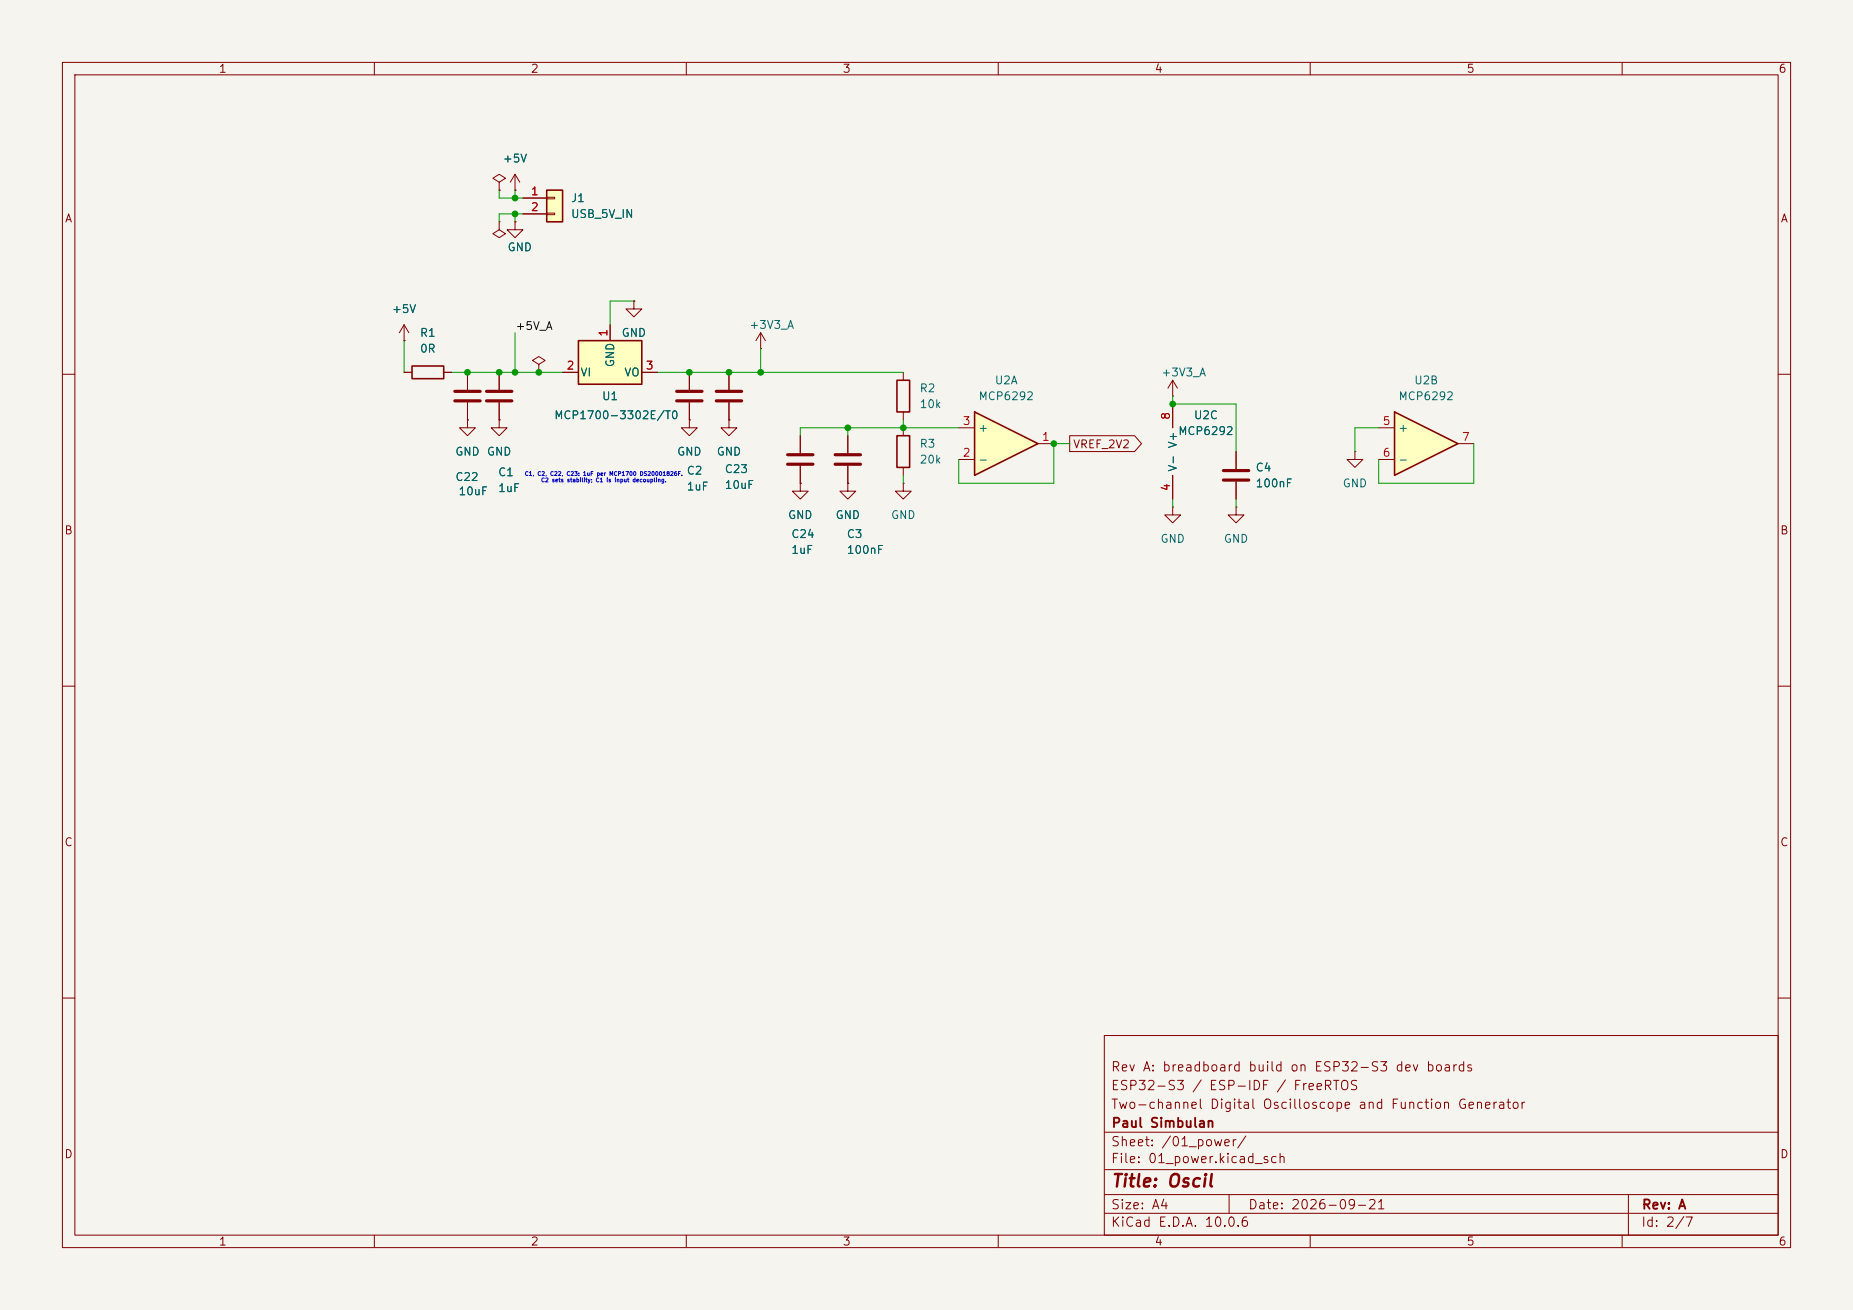
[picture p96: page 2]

C1, C2, C22, C23: 1uF per MCP1700 DS20001826F. C2 sets stability; C1 is input decoupling. U1 MCP1700-3302E/T0 GND

Rev A: breadboard build on ESP32-S3 dev boards
ESP32-S3 / ESP-IDF / FreeRTOS
Two-channel Digital Oscilloscope and Function Generator
Paul Simbulan
Sheet: /01_power/
File: 01_power.kicad_sch
Title: Oscil

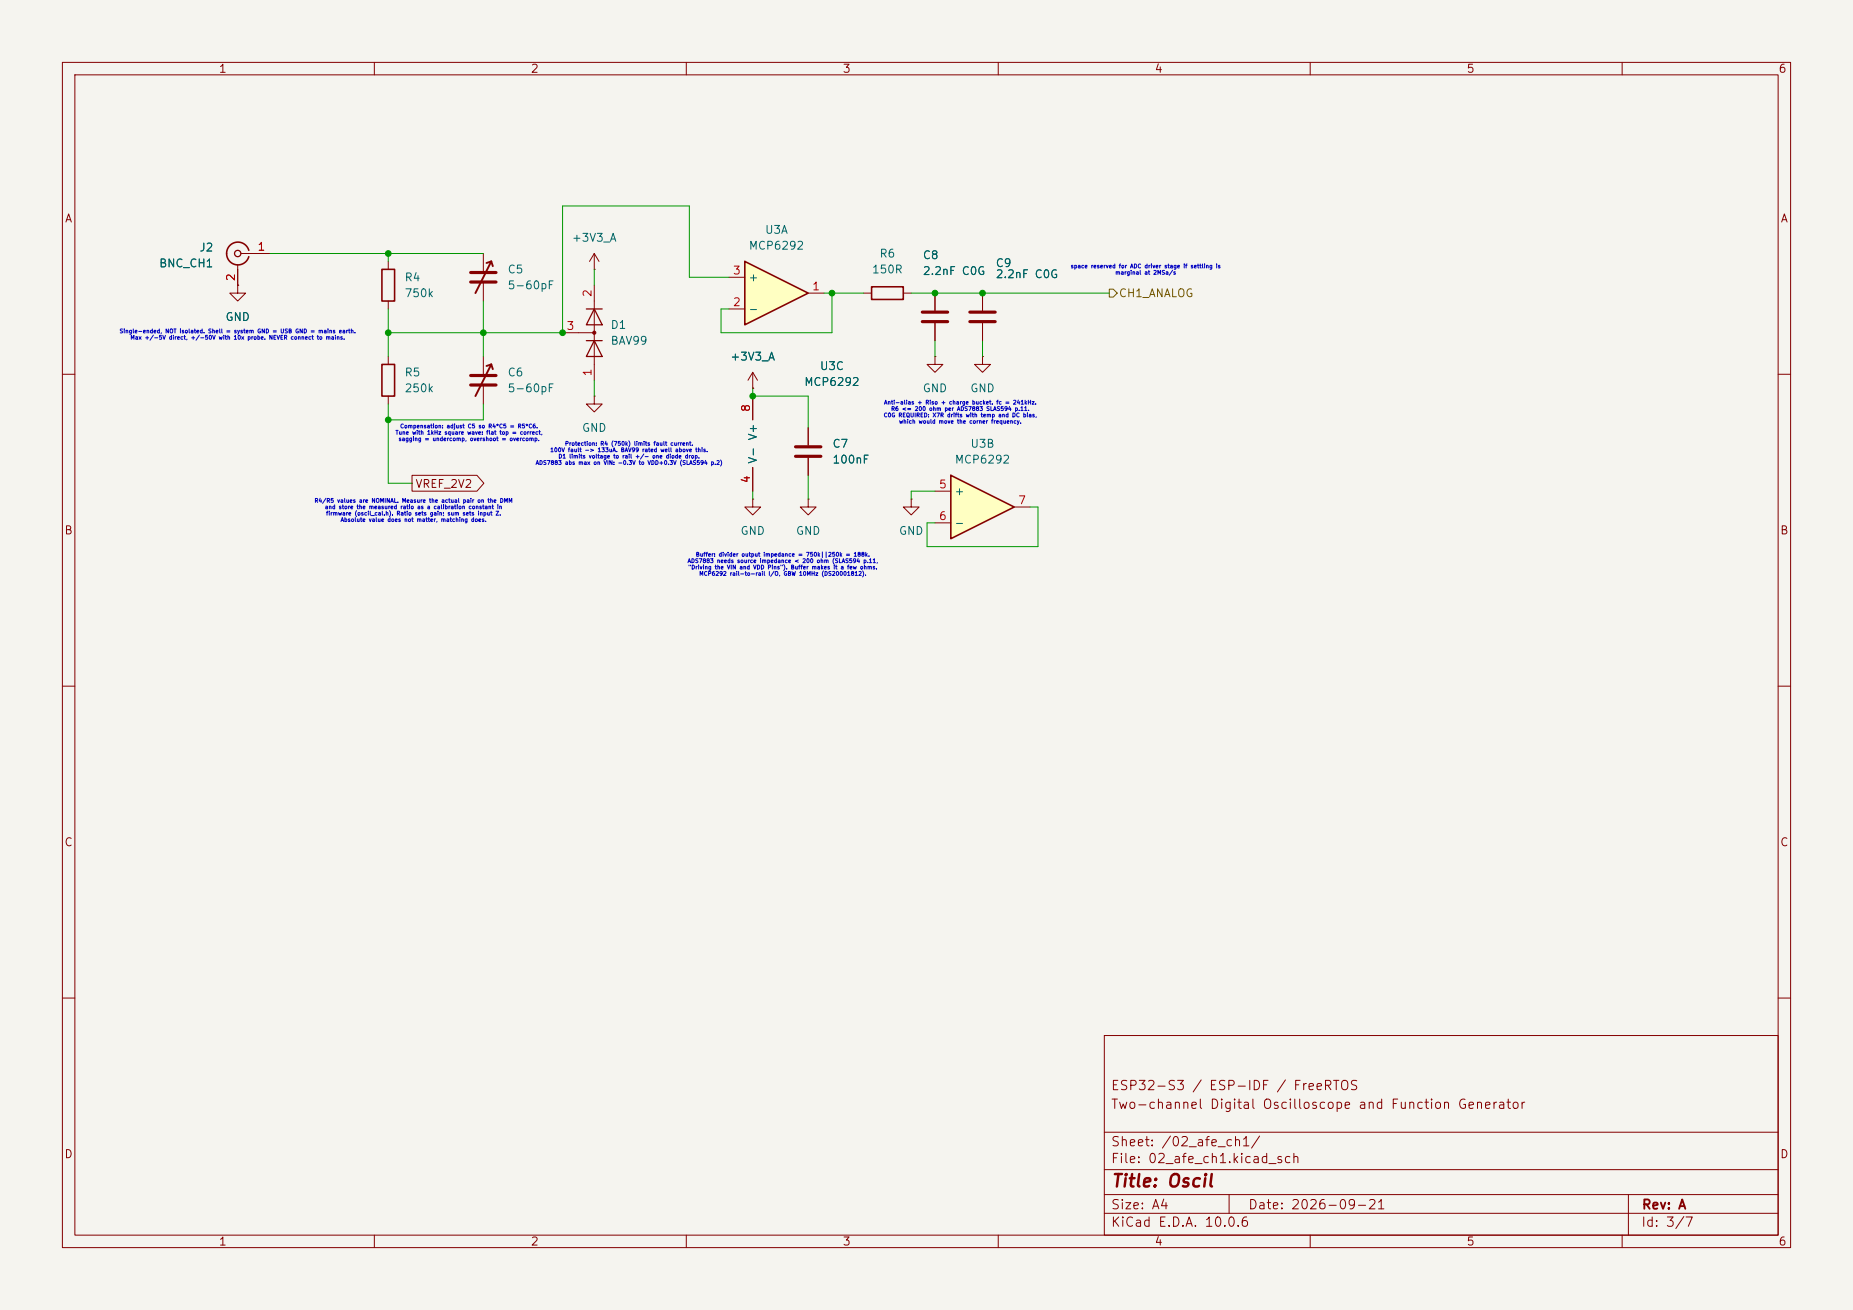
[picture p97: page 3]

R4/R5 values are NOMINAL. Measure the actual pair on the DMM
and store the measured ratio as a calibration constant in

ESP32-S3 / ESP-IDF / FreeRTOS
Two-channel Digital Oscilloscope and Function Generator

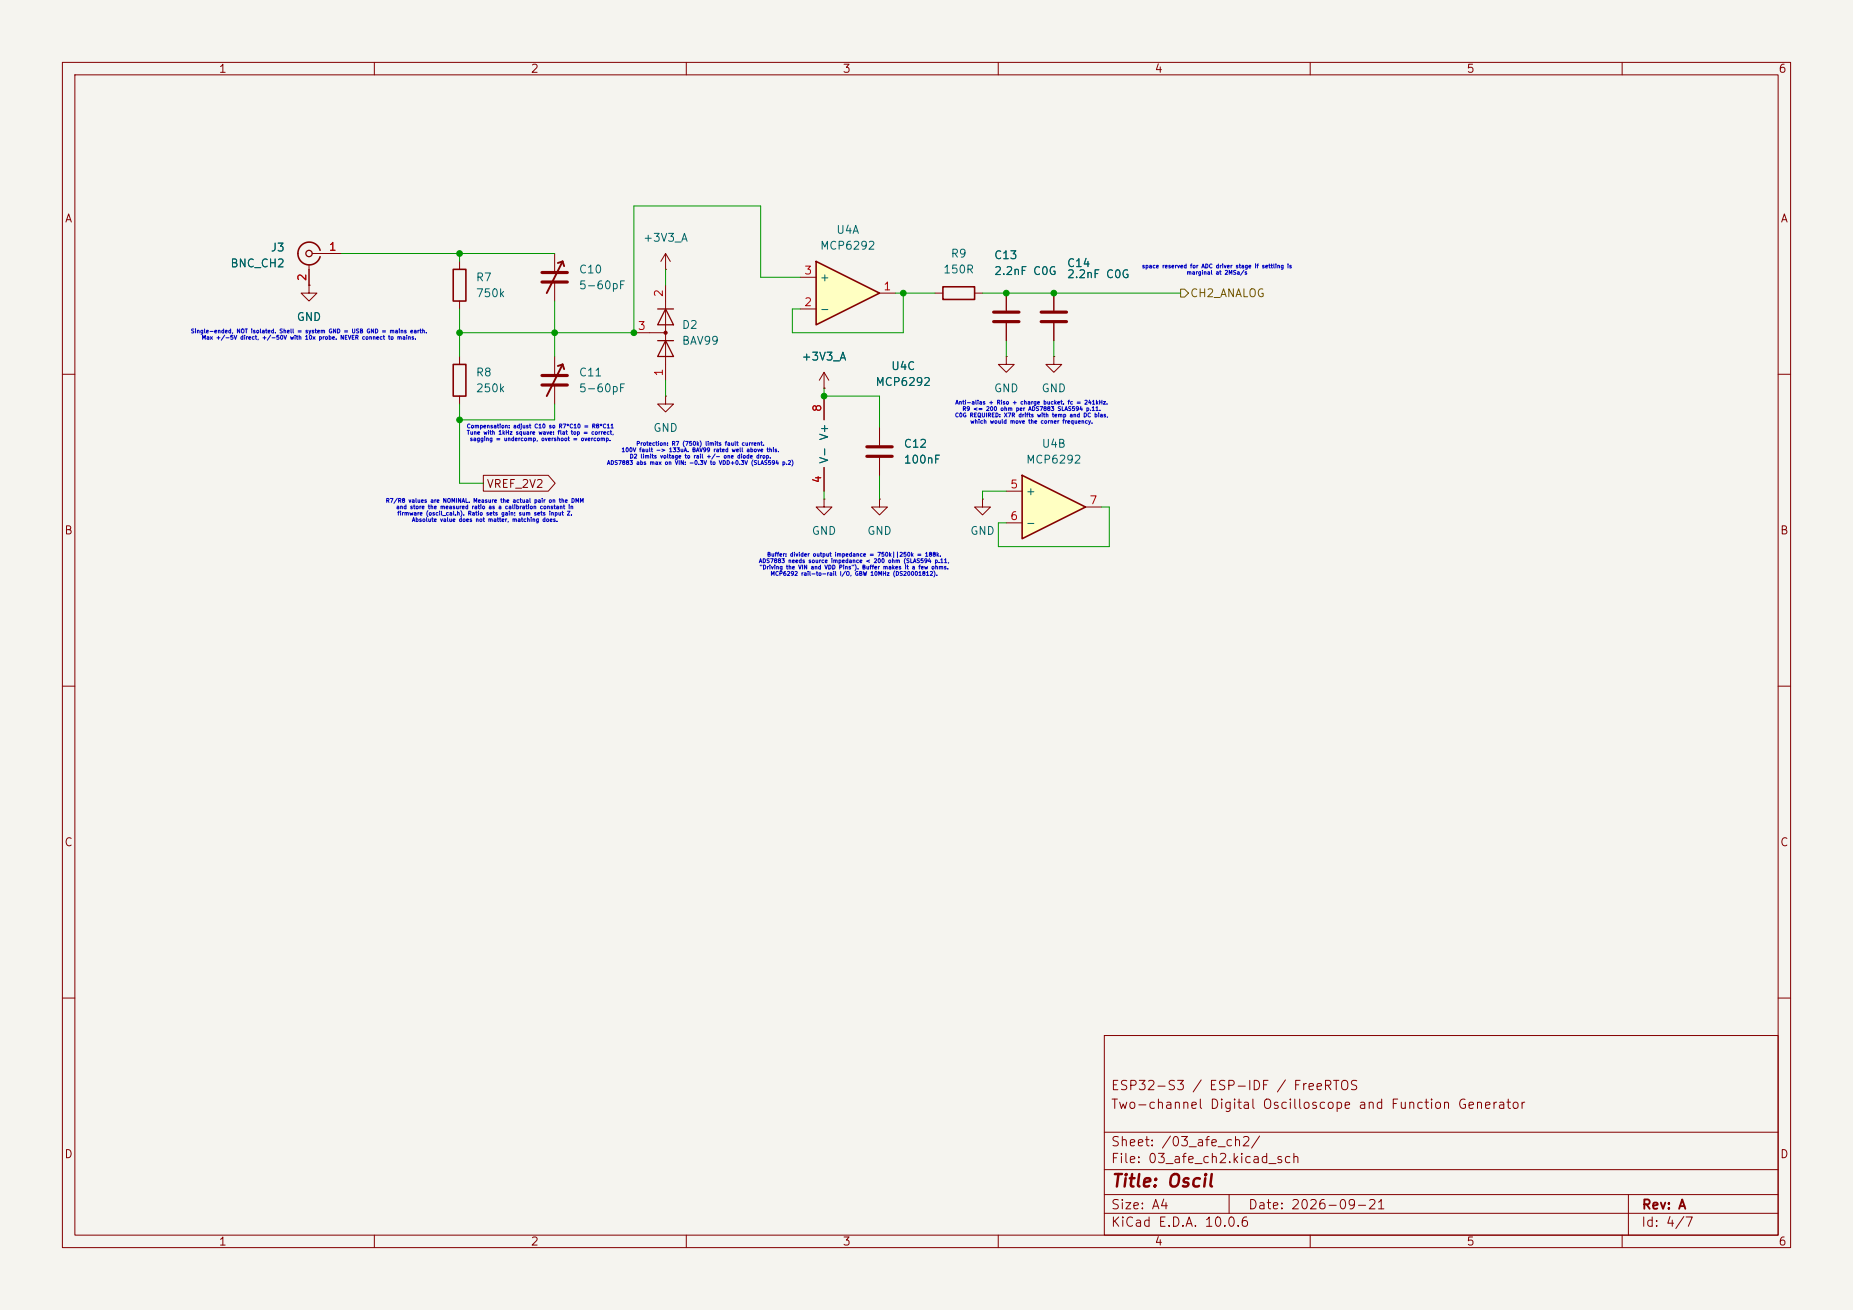
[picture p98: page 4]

and store the measured ratio as a calibration constant in

ESP32-S3 / ESP-IDF / FreeRTOS
Two-channel Digital Oscilloscope and Function Generator

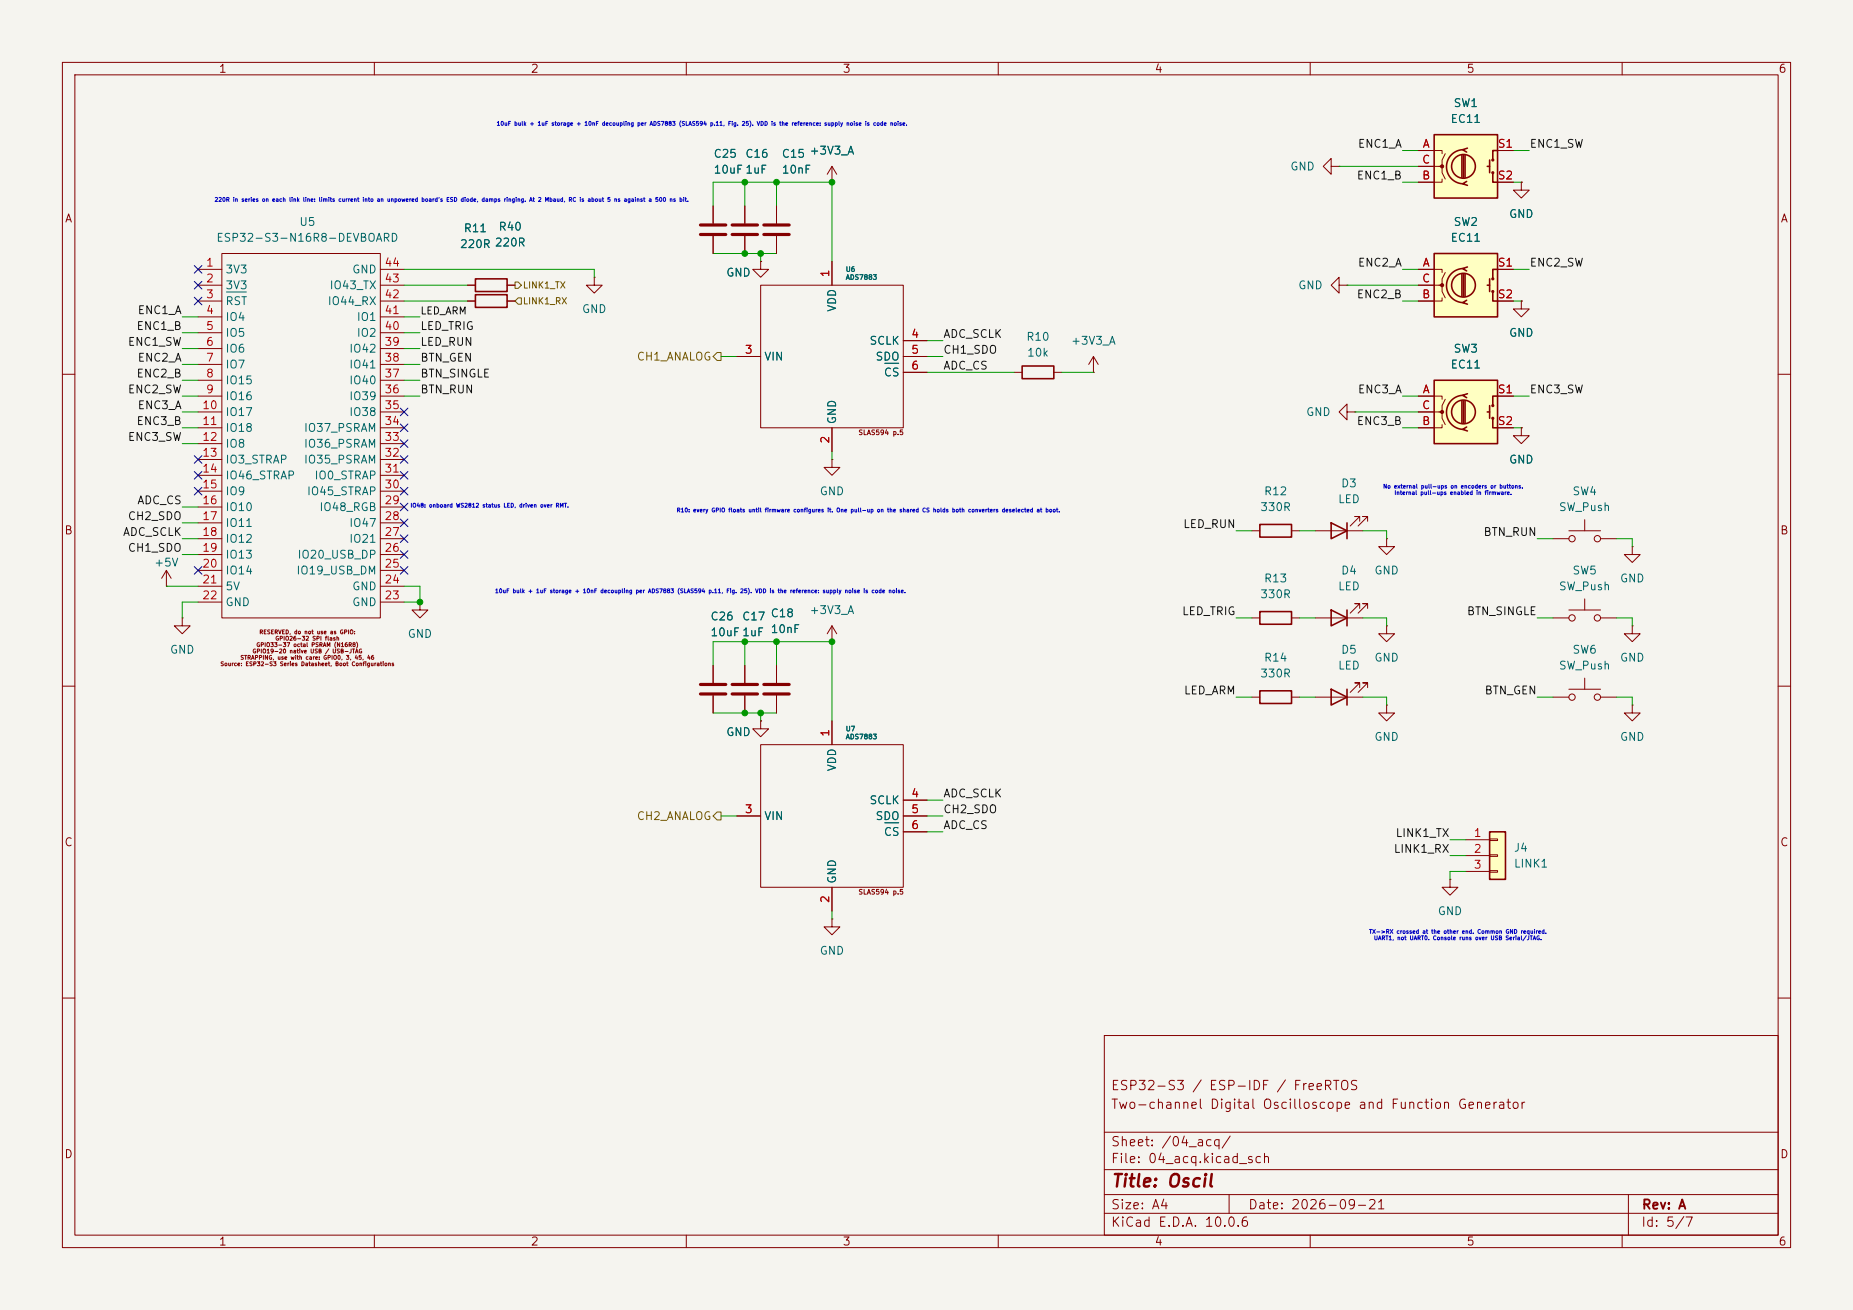
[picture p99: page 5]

Source: ESP32-S3 Series Datasheet, Boot Configurations 3V3 1

Internal pull-ups enabled in firmware.

R10: every GPIO floats until firmware configures it. One pull-up on the shared CS holds both converters deselected at boot.

10uF bulk + 1uF storage + 10nF decoupling per ADS7883 (SLAS594 p.11, Fig. 25). VDD is the reference: supply noise is code noise.

RESERVED, do not use as GPIO: GPIO26-32 SPI flash GPIO33-37 octal PSRAM (N16R8) GPIO19-20 native USB / USB-JTAG

STRAPPING, use with care: GPIO0, 3, 45, 46

TX->RX crossed at the other end. Common GND required. UART1, not UART0. Console runs over USB Serial/JTAG.

ESP32-S3 / ESP-IDF / FreeRTOS
Two-channel Digital Oscilloscope and Function Generator

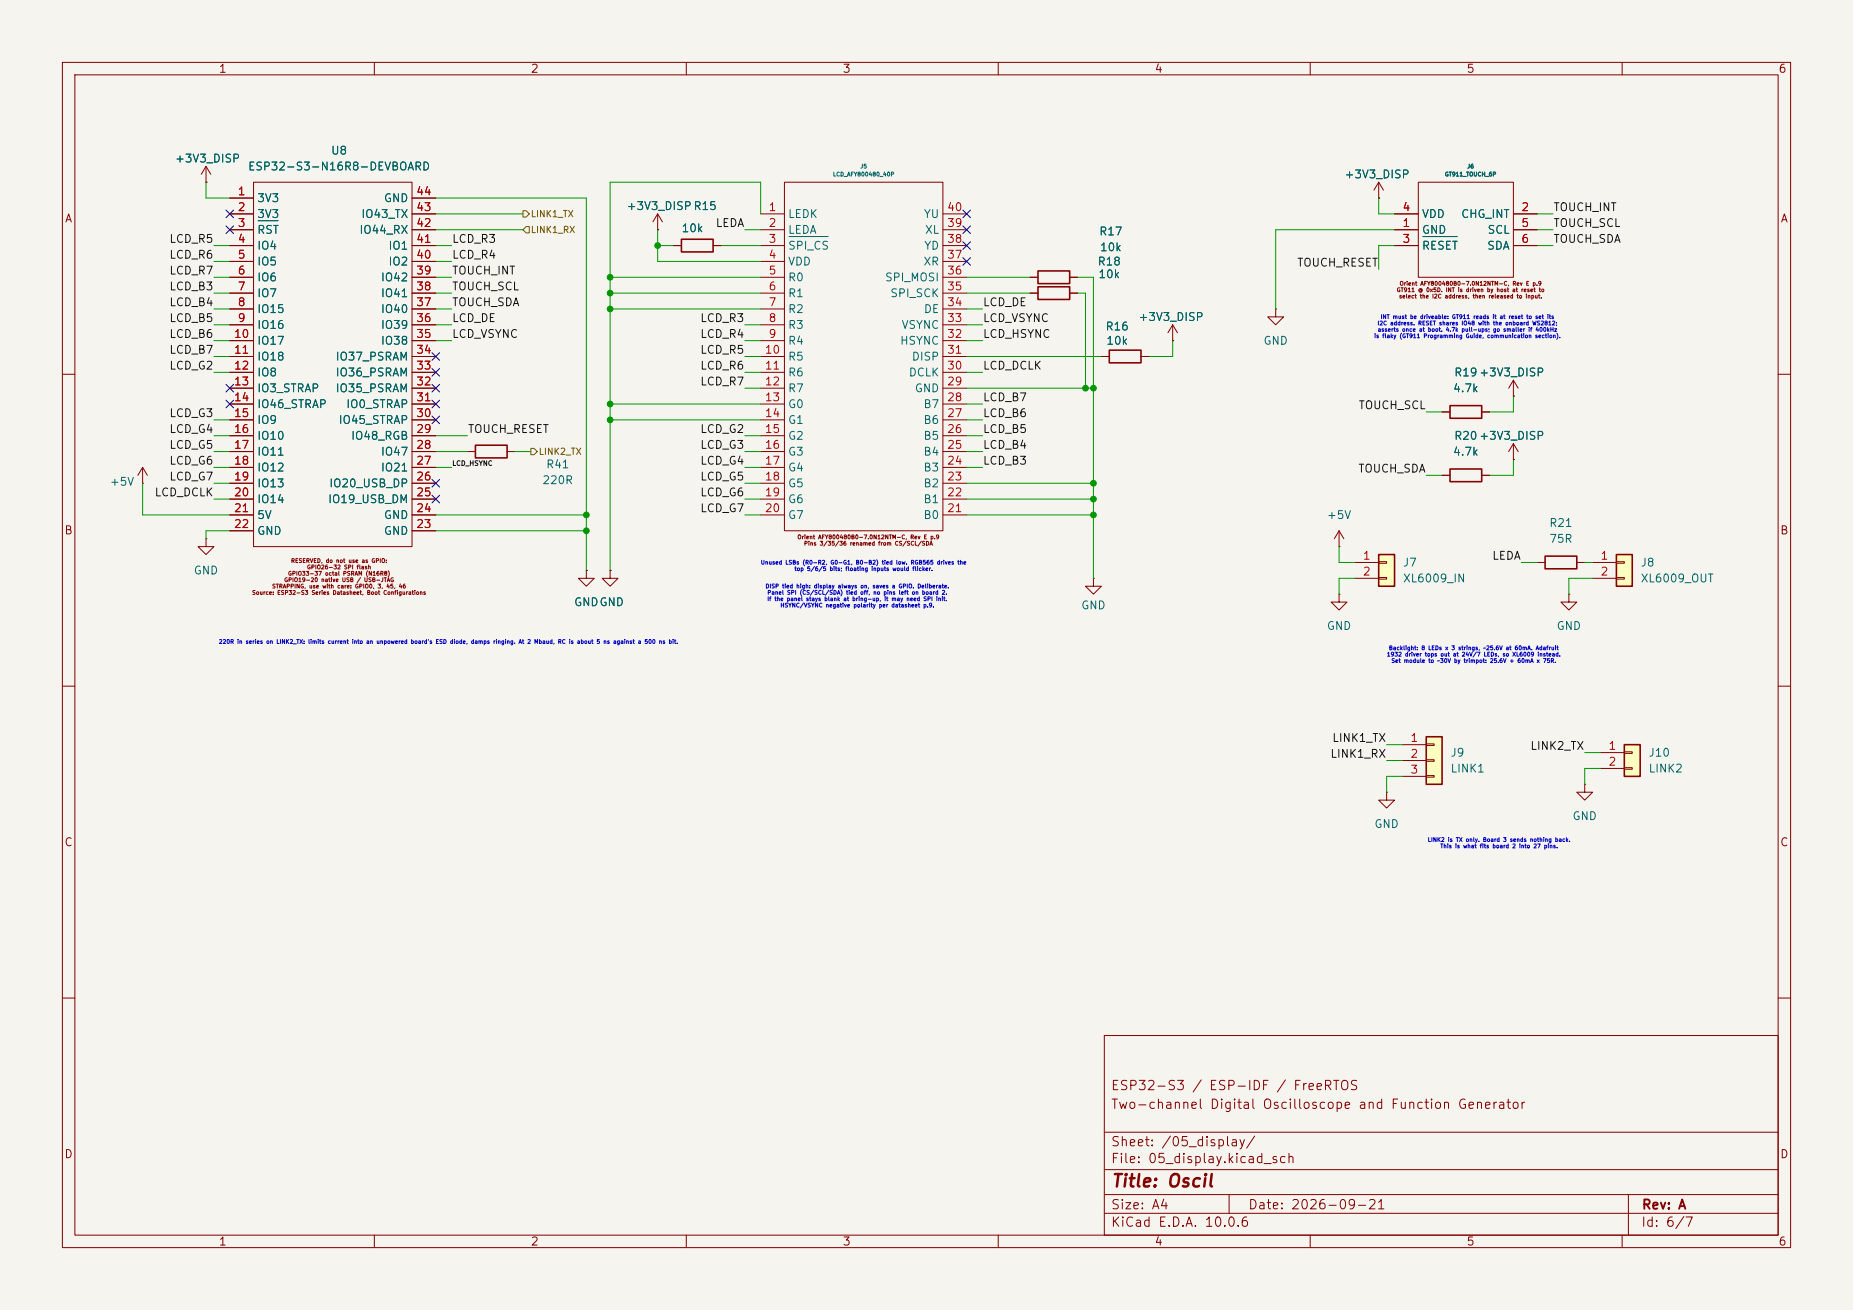
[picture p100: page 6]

ESP32-S3-N16R8-DEVBOARD
Source: ESP32-S3 Series Datasheet, Boot Configurations 3V3 1

is flaky (GT911 Programming Guide, communication section). GND U8
Orient AFY800480B0-7.0N12NTM-C, Rev E p.9 Pins 3/35/36 renamed from CS/SCL/SDA LEDK 1
LEDA 2
SPI_CS 3

Orient AFY800480B0-7.0N12NTM-C, Rev E p.9 GT911 @ 0x5D. INT is driven by host at reset to

INT must be driveable: GT911 reads it at reset to set its
I2C address. RESET shares IO48 with the onboard WS2812; asserts once at boot. 4.7k pull-ups; go smaller if 400kHz

top 5/6/5 bits; floating inputs would flicker. 220R in series on LINK2_TX: limits current into an unpowered board's ESD diode, damps ringing. At 2 Mbaud, RC is about 5 ns against a 500 ns bit.

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

STRAPPING, use with care: GPIO0, 3, 45, 46

LINK2 is TX only. Board 3 sends nothing back. This is what fits board 2 into 27 pins. DISP tied high: display always on, saves a GPIO. Deliberate. Panel SPI (CS/SCL/SDA) tied off, no pins left on board 2.

ESP32-S3 / ESP-IDF / FreeRTOS
Two-channel Digital Oscilloscope and Function Generator

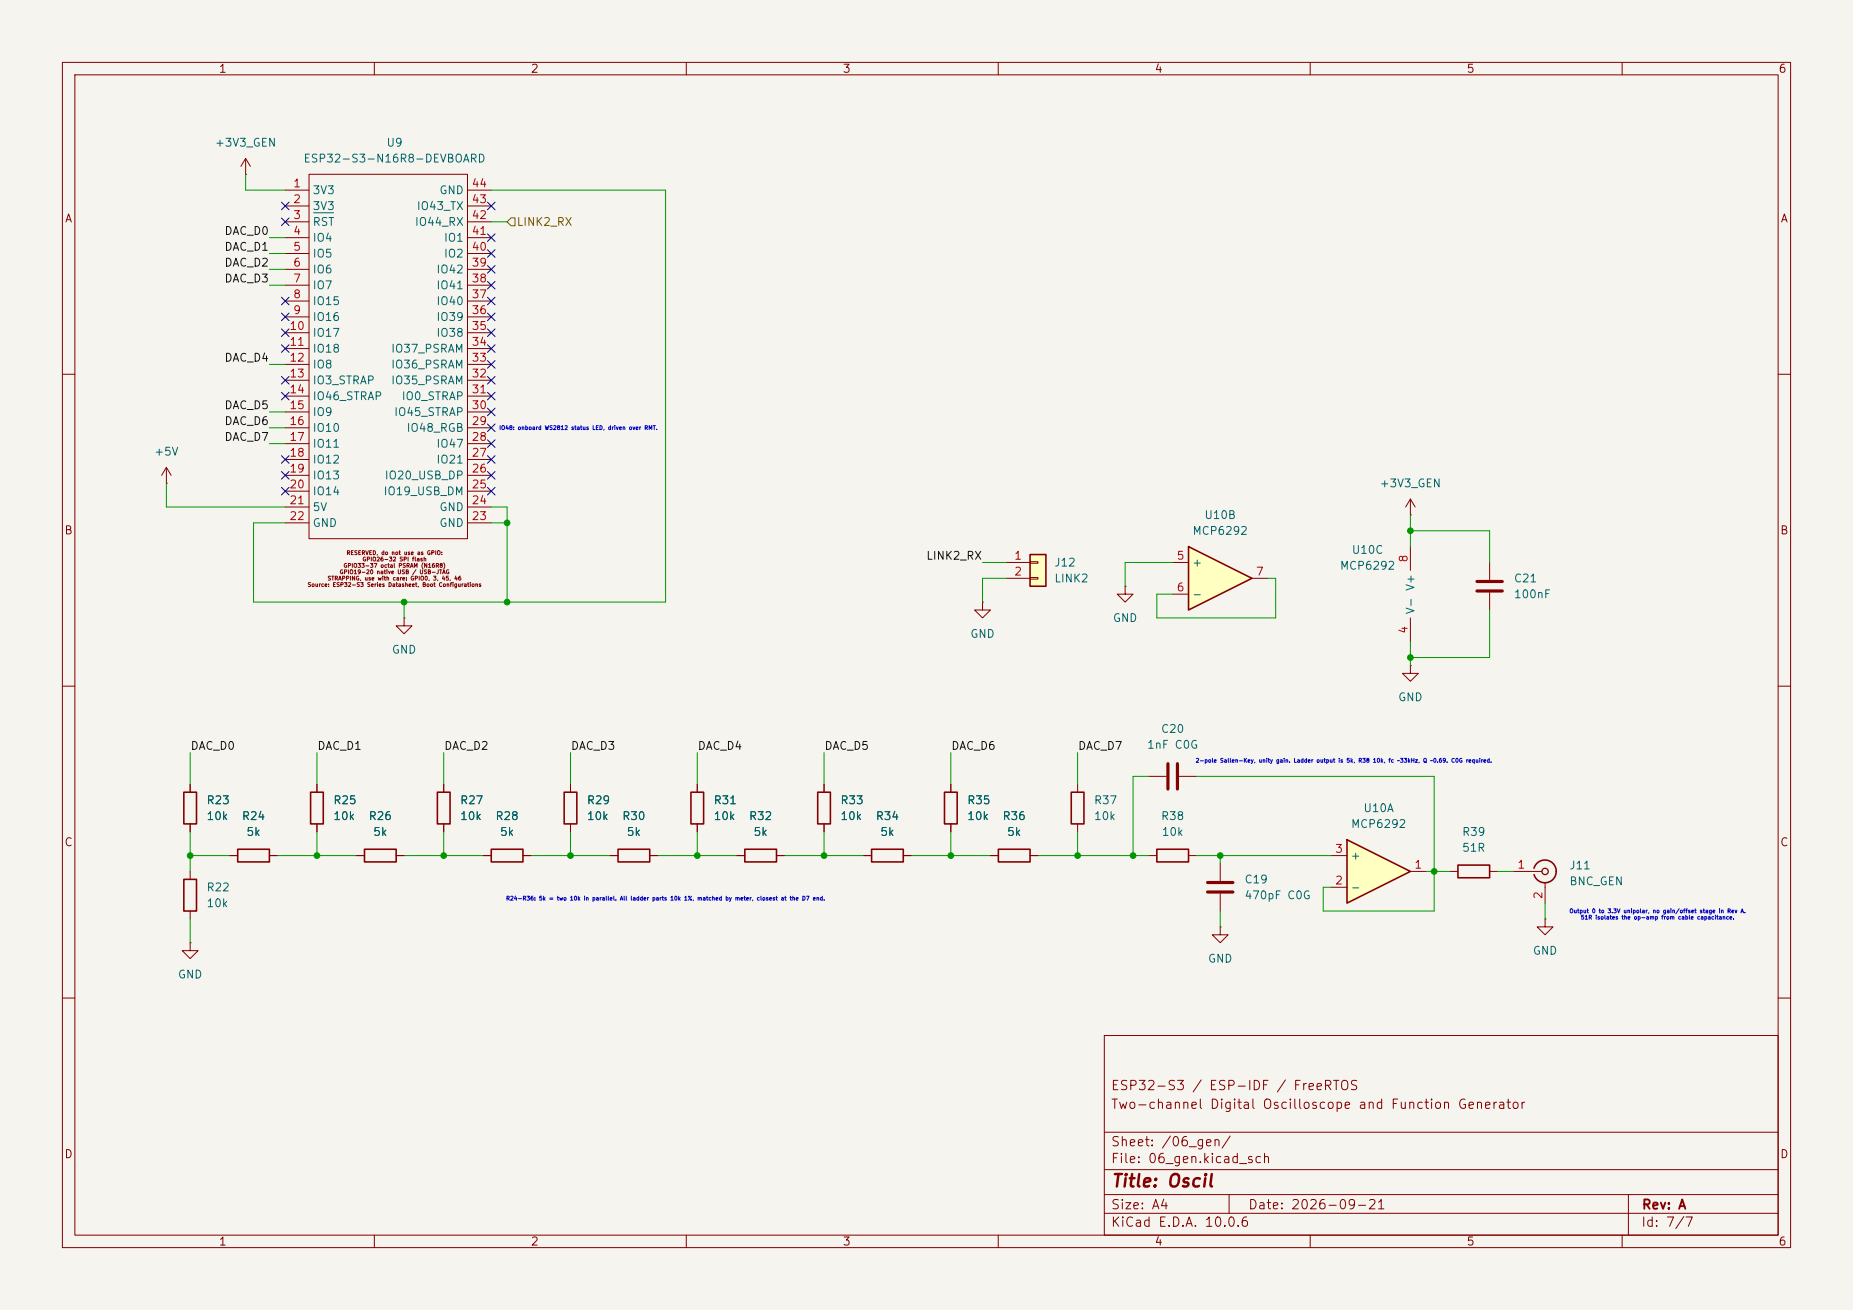
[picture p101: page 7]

Source: ESP32-S3 Series Datasheet, Boot Configurations 3V3 1
IO48: onboard WS2812 status LED, driven over RMT. R28

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

STRAPPING, use with care: GPIO0, 3, 45, 46

ESP32-S3 / ESP-IDF / FreeRTOS
Two-channel Digital Oscilloscope and Function Generator

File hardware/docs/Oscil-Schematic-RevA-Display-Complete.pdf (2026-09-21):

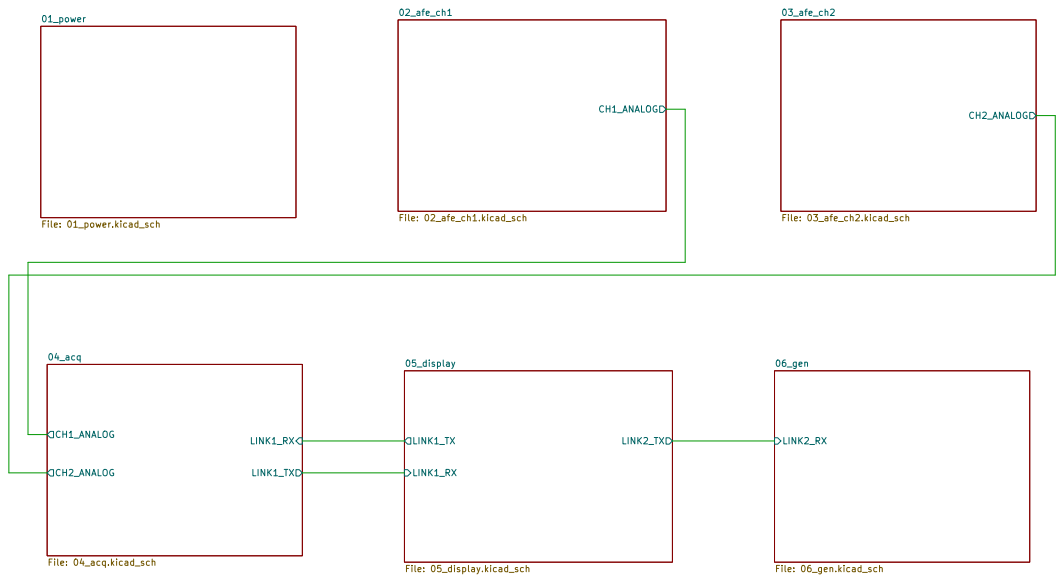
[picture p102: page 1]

ESP32-S3 / ESP-IDF / FreeRTOS
Two-channel Digital Oscilloscope and Function Generator

Size: A3 | Rev: 0.1 | F Date: 2026-09-18
KiCad E.D.A. 10.0.6 | Id: 1/7

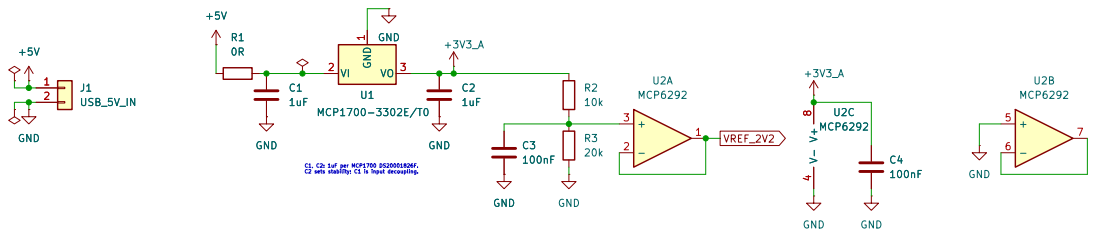
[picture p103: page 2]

ESP32-S3 / ESP-IDF / FreeRTOS
Two-channel Digital Oscilloscope and Function Generator

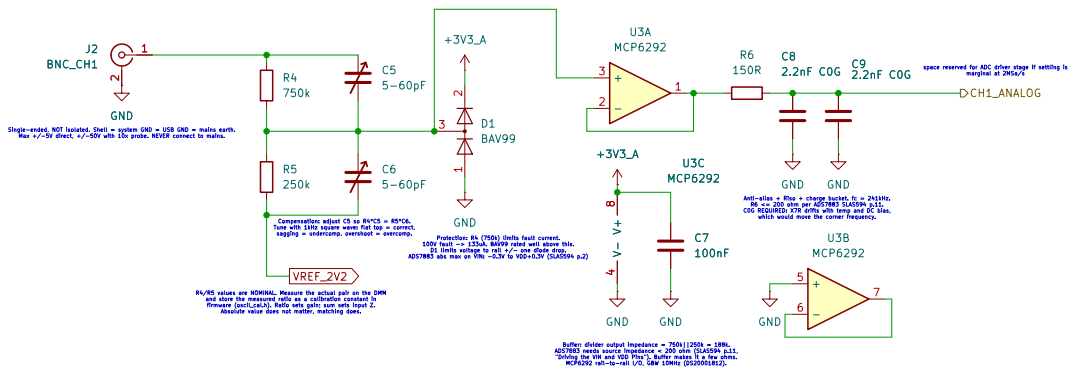
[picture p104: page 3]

R4/R5 values are NOMINAL. Measure the actual pair on the DMM
and store the measured ratio as a calibration constant in

ESP32-S3 / ESP-IDF / FreeRTOS
Two-channel Digital Oscilloscope and Function Generator

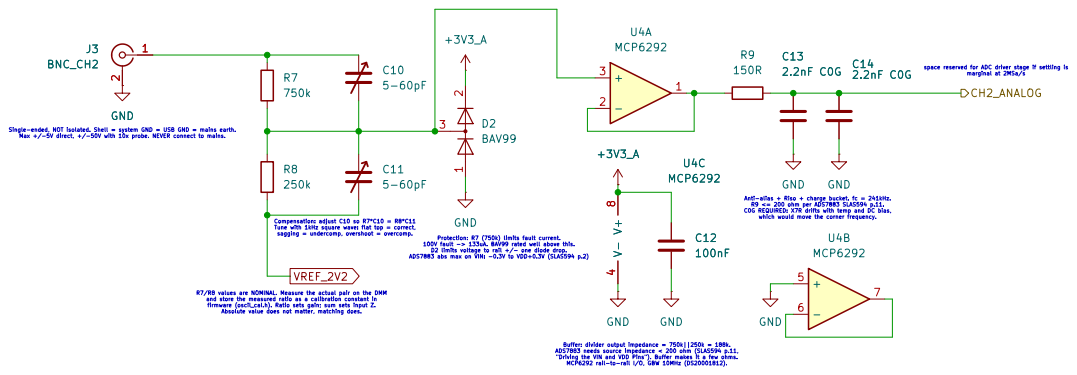
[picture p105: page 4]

and store the measured ratio as a calibration constant in

ESP32-S3 / ESP-IDF / FreeRTOS
Two-channel Digital Oscilloscope and Function Generator

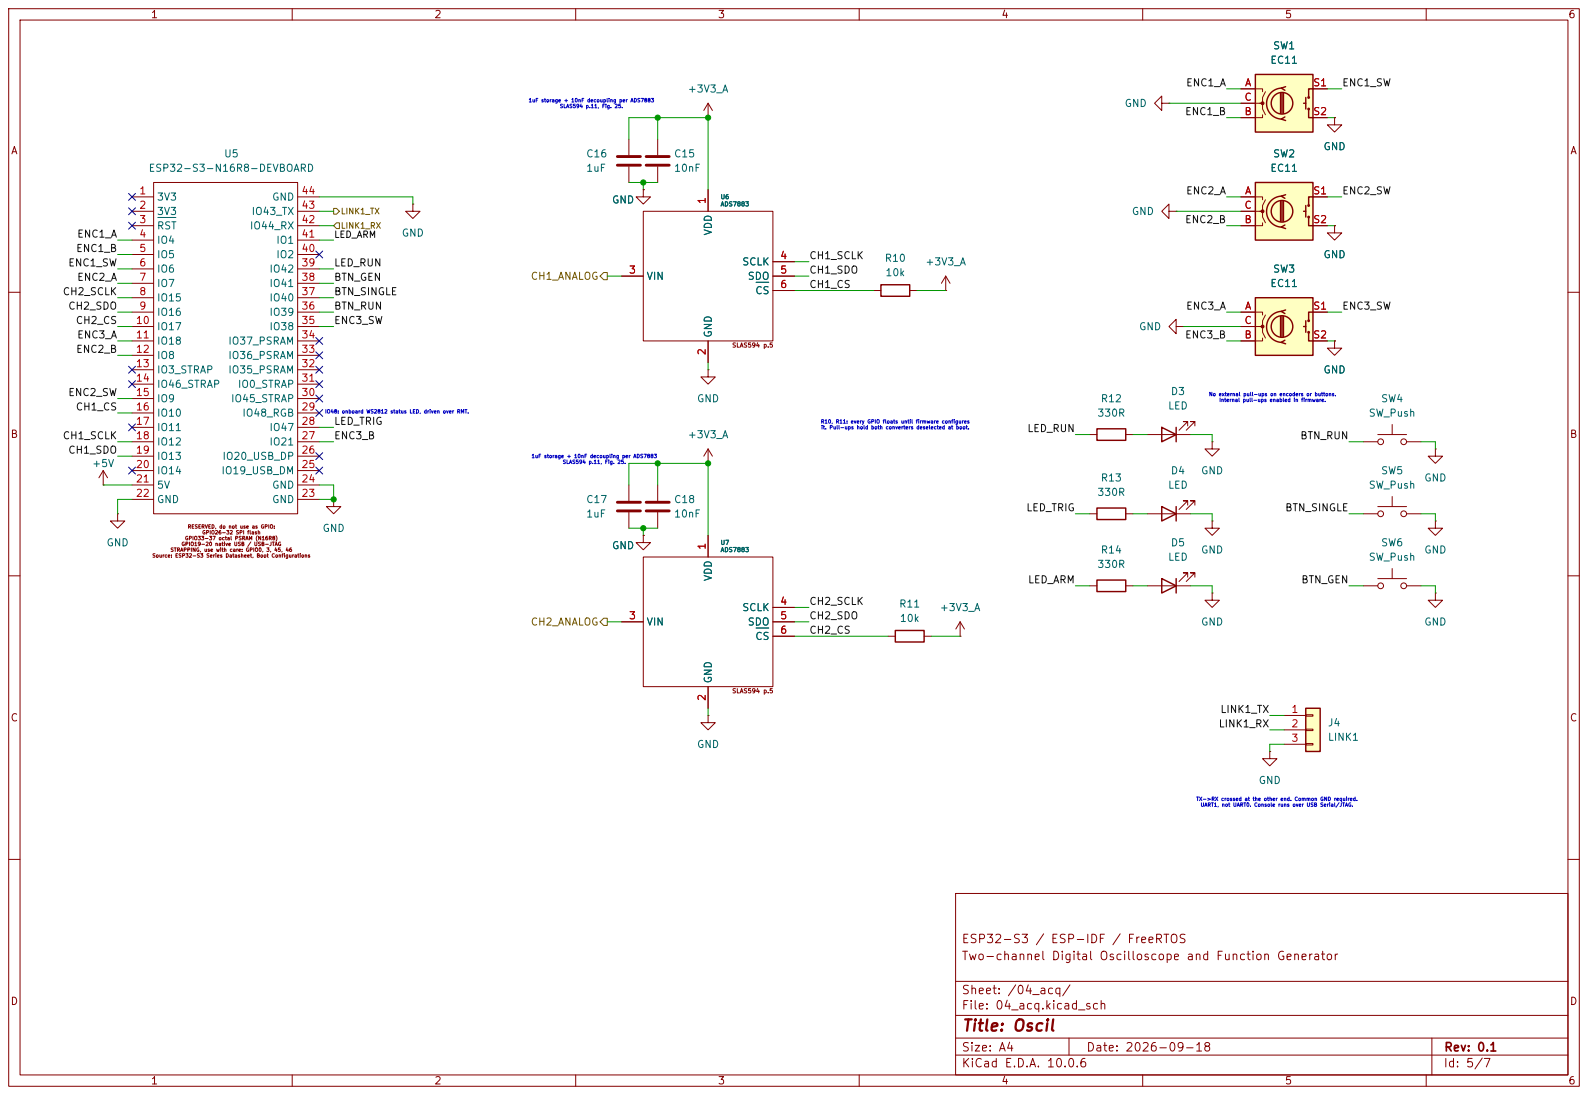
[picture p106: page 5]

SLAS594 p.11, Fig. 25. GND
Source: ESP32-S3 Series Datasheet, Boot Configurations 3V3 1

ESP32-S3 / ESP-IDF / FreeRTOS +3V3_A GND

Internal pull-ups enabled in firmware.

R10, R11: every GPIO floats until firmware configures

it. Pull-ups hold both converters deselected at boot. 1uF storage + 10nF decoupling per ADS7883

RESERVED, do not use as GPIO: GPIO26-32 SPI flash GPIO33-37 octal PSRAM (N16R8) GPIO19-20 native USB / USB-JTAG

STRAPPING, use with care: GPIO0, 3, 45, 46

TX->RX crossed at the other end. Common GND required. UART1, not UART0. Console runs over USB Serial/JTAG.

Two-channel Digital Oscilloscope and Function Generator


GND +3V3_DISP
Source: ESP32-S3 Series Datasheet, Boot Configurations 3V3 1

Orient AFY800480B0-7.0N12NTM-C, Rev E p.9 Pins 3/35/36 renamed from CS/SCL/SDA LEDK 1
LEDA 2
SPI_CS 3

Orient AFY800480B0-7.0N12NTM-C, Rev E p.9 GT911 @ 0x5D. INT is driven by host at reset to

INT must be driveable: GT911 reads it at reset to set its
I2C address. RESET shares IO48 with the onboard WS2812; asserts once at boot. 4.7k pull-ups; go smaller if 400kHz

is flaky (GT911 Programming Guide, communication section). Backlight: 8 LEDs x 3 strings, ~25.6V at 60mA. Adafruit 1932 driver tops out at 24V/7 LEDs, so XL6009 instead. Set module to ~30V by trimpot: 25.6V + 60mA x 75R. DISP tied high: display always on, saves a GPIO. Deliberate. Panel SPI (CS/SCL/SDA) tied off, no pins left on board 2.

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

If the panel stays blank at bring-up, it may need SPI init. HSYNC/VSYNC negative polarity per datasheet p.9. Unused LSBs (R0-R2, G0-G1, B0-B2) tied low. RGB565 drives the

STRAPPING, use with care: GPIO0, 3, 45, 46

ESP32-S3 / ESP-IDF / FreeRTOS
Two-channel Digital Oscilloscope and Function Generator


ESP32-S3-N16R8-DEVBOARD
Source: ESP32-S3 Series Datasheet, Boot Configurations 3V3 1

IO48: onboard WS2812 status LED, driven over RMT. R25

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

STRAPPING, use with care: GPIO0, 3, 45, 46

Output 0 to 3.3V unipolar, no gain/offset stage in Rev A. 51R isolates the op-amp from cable capacitance. 2-pole Sallen-Key, unity gain. Ladder output is 10k, R38 10k. fc ~23kHz, Q ~0.73. C0G required.

ESP32-S3 / ESP-IDF / FreeRTOS
Two-channel Digital Oscilloscope and Function Generator

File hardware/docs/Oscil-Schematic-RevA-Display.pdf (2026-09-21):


ESP32-S3 / ESP-IDF / FreeRTOS
Two-channel Digital Oscilloscope and Function Generator

Size: A3 | Rev: 0.1 | F Date: 2026-09-18
KiCad E.D.A. 10.0.6 | Id: 1/7


ESP32-S3 / ESP-IDF / FreeRTOS
Two-channel Digital Oscilloscope and Function Generator


R4/R5 values are NOMINAL. Measure the actual pair on the DMM
and store the measured ratio as a calibration constant in

ESP32-S3 / ESP-IDF / FreeRTOS
Two-channel Digital Oscilloscope and Function Generator


and store the measured ratio as a calibration constant in

ESP32-S3 / ESP-IDF / FreeRTOS
Two-channel Digital Oscilloscope and Function Generator


SLAS594 p.11, Fig. 25. GND
Source: ESP32-S3 Series Datasheet, Boot Configurations 3V3 1

Internal pull-ups enabled in firmware.

R10, R11: every GPIO floats until firmware configures

it. Pull-ups hold both converters deselected at boot. 1uF storage + 10nF decoupling per ADS7883

RESERVED, do not use as GPIO: GPIO26-32 SPI flash GPIO33-37 octal PSRAM (N16R8) GPIO19-20 native USB / USB-JTAG

STRAPPING, use with care: GPIO0, 3, 45, 46

TX->RX crossed at the other end. Common GND required. UART1, not UART0. Console runs over USB Serial/JTAG.

ESP32-S3 / ESP-IDF / FreeRTOS
Two-channel Digital Oscilloscope and Function Generator


GND +3V3_DISP
Source: ESP32-S3 Series Datasheet, Boot Configurations 3V3 1

Orient AFY800480B0-7.0N12NTM-C, Rev E p.9 Pins 3/35/36 renamed from CS/SCL/SDA LEDK 1
LEDA 2
SPI_CS 3

Orient AFY800480B0-7.0N12NTM-C, Rev E p.9 GT911 @ 0x5D. INT is driven by host at reset to

INT must be driveable: GT911 reads it at reset to set its
I2C address. RESET shares IO48 with the onboard WS2812; asserts once at boot. 4.7k pull-ups; go smaller if 400kHz

is flaky (GT911 Programming Guide, communication section). Backlight: 8 LEDs x 3 strings, ~25.6V at 60mA. Adafruit 1932 driver tops out at 24V/7 LEDs, so XL6009 instead. Set module to ~30V by trimpot: 25.6V + 60mA x 75R. DISP tied high: display always on, saves a GPIO. Deliberate. Panel SPI (CS/SCL/SDA) tied off, no pins left on board 2.

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

If the panel stays blank at bring-up, it may need SPI init. HSYNC/VSYNC negative polarity per datasheet p.9. Unused LSBs (R0-R2, G0-G1, B0-B2) tied low. RGB565 drives the

STRAPPING, use with care: GPIO0, 3, 45, 46

ESP32-S3 / ESP-IDF / FreeRTOS
Two-channel Digital Oscilloscope and Function Generator


ESP32-S3 / ESP-IDF / FreeRTOS
Two-channel Digital Oscilloscope and Function Generator

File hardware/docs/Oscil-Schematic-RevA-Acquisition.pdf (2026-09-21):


ESP32-S3 / ESP-IDF / FreeRTOS
Two-channel Digital Oscilloscope and Function Generator

Size: A3 | Rev: 0.1 | F Date: 2026-09-18
KiCad E.D.A. 10.0.6 | Id: 1/7


ESP32-S3 / ESP-IDF / FreeRTOS
Two-channel Digital Oscilloscope and Function Generator


R4/R5 values are NOMINAL. Measure the actual pair on the DMM
and store the measured ratio as a calibration constant in

ESP32-S3 / ESP-IDF / FreeRTOS
Two-channel Digital Oscilloscope and Function Generator


and store the measured ratio as a calibration constant in

ESP32-S3 / ESP-IDF / FreeRTOS
Two-channel Digital Oscilloscope and Function Generator


SLAS594 p.11, Fig. 25. GND
Source: ESP32-S3 Series Datasheet, Boot Configurations 3V3 1

ESP32-S3 / ESP-IDF / FreeRTOS +3V3_A GND

Internal pull-ups enabled in firmware.

R10, R11: every GPIO floats until firmware configures

it. Pull-ups hold both converters deselected at boot. 1uF storage + 10nF decoupling per ADS7883

RESERVED, do not use as GPIO: GPIO26-32 SPI flash GPIO33-37 octal PSRAM (N16R8) GPIO19-20 native USB / USB-JTAG

STRAPPING, use with care: GPIO0, 3, 45, 46

TX->RX crossed at the other end. Common GND required. UART1, not UART0. Console runs over USB Serial/JTAG.

Two-channel Digital Oscilloscope and Function Generator


ESP32-S3 / ESP-IDF / FreeRTOS
Two-channel Digital Oscilloscope and Function Generator


ESP32-S3 / ESP-IDF / FreeRTOS
Two-channel Digital Oscilloscope and Function Generator

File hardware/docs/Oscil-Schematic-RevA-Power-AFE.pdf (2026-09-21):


ESP32-S3 / ESP-IDF / FreeRTOS
Two-channel Digital Oscilloscope and Function Generator

Size: A3 | Rev: 0.1 | F Date: 2026-09-18
KiCad E.D.A. 10.0.6 | Id: 1/7


ESP32-S3 / ESP-IDF / FreeRTOS
Two-channel Digital Oscilloscope and Function Generator


and store the measured ratio as a calibration constant in

ESP32-S3 / ESP-IDF / FreeRTOS
Two-channel Digital Oscilloscope and Function Generator


Tune with 1kHz square wave: flat top = correct, sagging = undercomp, overshoot = overcomp. GND

and store the measured ratio as a calibration constant in

ESP32-S3 / ESP-IDF / FreeRTOS
Two-channel Digital Oscilloscope and Function Generator


ESP32-S3 / ESP-IDF / FreeRTOS
Two-channel Digital Oscilloscope and Function Generator


ESP32-S3 / ESP-IDF / FreeRTOS
Two-channel Digital Oscilloscope and Function Generator


ESP32-S3 / ESP-IDF / FreeRTOS
Two-channel Digital Oscilloscope and Function Generator

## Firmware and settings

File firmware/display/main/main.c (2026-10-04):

#include <stdio.h>
#include <inttypes.h>
#include "freertos/FreeRTOS.h"
#include "freertos/task.h"
#include "esp_log.h"
#include "esp_chip_info.h"
#include "esp_flash.h"
#include "esp_psram.h"
#include "oscil_pins_display.h"
#include "lcd.h"
#include "lcd_test.h"
#include "gui.h"
#include "gui_test.h"
#include "touch.h"
#include "touch_test.h"
#include "links.h"
#include "scope_view.h"
#include "ui.h"
#include "settings.h"
#include "net.h"
#include "ota.h"
#include "ui_sys.h"
#include "account.h"
#include "account_test.h"
#include "upload.h"

static const char *TAG = "disp";


void app_main(void)
{
    esp_chip_info_t chip;
    esp_chip_info(&chip);
    uint32_t flash_bytes = 0;
    esp_flash_get_size(NULL, &flash_bytes);
    ESP_LOGI(TAG, "Oscil board 2: display");
    ESP_LOGI(TAG, "cores %d, silicon v%d.%d, flash %" PRIu32 " MB, psram %u MB",
             chip.cores, chip.revision / 100, chip.revision % 100,
             flash_bytes / (1024 * 1024), (unsigned)(esp_psram_get_size() / (1024 * 1024)));
    // Status LED retired: GPIO48 is TOUCH_RESET, and its 30 us masked window
    // would upset the RGB bounce-buffer refill interrupt.

    ESP_ERROR_CHECK(settings_init());
    ESP_ERROR_CHECK(account_init());

    bool update_mode = false;
    esp_err_t e = ota_boot_if_requested(&update_mode);
    if (e != ESP_OK) ESP_LOGE(TAG, "update boot: %s", esp_err_to_name(e));
    if (update_mode) return;                    // OTA task owns this boot; no LCD or UI

    ui_settings_t s;
    if (settings_load(&s) != ESP_OK) { ui_defaults(&s); ESP_LOGW(TAG, "settings: defaults"); }
    s.gen.on = 0;                                                   // generator off at power-up

    esp_lcd_panel_handle_t panel = lcd_start(10, 2);                // 10-line bounce buffers, 2 frame buffers
    lv_display_t *disp = gui_start(panel);
    touch_start(disp);                                              // failure is logged; the self-test sees it
    const links_handlers_t lh = { .on_frame = scope_view_submit, .on_key = ui_on_key,
                                  .on_acq_state = ui_on_acq_state, .on_cal = scope_view_set_cal };
    ESP_ERROR_CHECK(links_start(&lh));
    const ui_hooks_t hooks = {
        .changed = settings_mark_dirty,
        .save = upload_save,
        .sys = ui_sys_toggle
    };
    ui_start(&s, &hooks);
    ESP_ERROR_CHECK(upload_start());
    net_start();
    ota_confirm_or_roll_back();                                     // no-op unless this image is new
    ESP_LOGI(TAG, "firmware %s", ota_version());

    // test_lcd(panel);
    //test_account("paul_test", "hunter2hunter2");
}

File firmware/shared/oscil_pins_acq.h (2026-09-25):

#pragma once
// Board 1, acquisition. Source of truth: hardware/docs/pin-map.md
// Plain integers so host tests can include this without ESP-IDF.
// Comments give the Lonely Binary header pin.

// Both ADS7883s on SPI2 through IO_MUX, one clock and one chip select,
// data read on two lines at once (dual-line read)
#define ACQ_ADC_SCLK      12  // header 18, FSPICLK, to both ADCs
#define ACQ_ADC_CS        10  // header 16, FSPICS0, to both ADCs, 10k pull-up
#define ACQ_CH1_SDO       13  // header 19, FSPIQ
#define ACQ_CH2_SDO       11  // header 17, FSPID

// Encoders, active low, internal pull-ups
#define ACQ_ENC1_A         4  // header 4
#define ACQ_ENC1_B         5  // header 5
#define ACQ_ENC1_SW        6  // header 6
#define ACQ_ENC2_A         7  // header 7
#define ACQ_ENC2_B        15  // header 8
#define ACQ_ENC2_SW       16  // header 9
#define ACQ_ENC3_A        17  // header 10
#define ACQ_ENC3_B        18  // header 11
#define ACQ_ENC3_SW        8  // header 12

// Buttons, active low, internal pull-ups
#define ACQ_BTN_RUN       39  // header 36
#define ACQ_BTN_SINGLE    40  // header 37
#define ACQ_BTN_GEN       41  // header 38

// Panel LEDs, active high, 330R each
#define ACQ_LED_RUN       42  // header 39
#define ACQ_LED_TRIG       2  // header 40
#define ACQ_LED_ARM        1  // header 41
#define ACQ_STATUS_RGB    48  // header 29, onboard WS2812

// LINK1 to board 2, UART1 (console is on USB Serial/JTAG)
#define ACQ_LINK1_TX      43  // header 43
#define ACQ_LINK1_RX      44  // header 42

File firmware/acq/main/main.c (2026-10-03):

#include <stdio.h>
#include <inttypes.h>
#include "freertos/FreeRTOS.h"
#include "esp_log.h"
#include "esp_chip_info.h"
#include "esp_flash.h"
#include "esp_psram.h"
#include "oscil_pins_acq.h"
#include "oscil_status.h"
#include "oscil_pinwalk.h"
#include "spi_speed.h"
#include "panel.h"
#include "panel_test.h"        
#include "adc_test.h"
#include "burst_test.h"
#include "testsig.h"
#include "acq_task.h"
#include "link_test.h"
#include "nvs_flash.h"
#include "cal.h"
#include "cal_test.h"

static const char *TAG = "acq";

/**
 * 
 static const oscil_pin_t ACQ_PINS[] = {
    { ACQ_ENC1_A, "ENC1_A" }, { ACQ_ENC1_B, "ENC1_B" }, { ACQ_ENC1_SW, "ENC1_SW" },
    { ACQ_ENC2_A, "ENC2_A" }, { ACQ_ENC2_B, "ENC2_B" }, { ACQ_ENC2_SW, "ENC2_SW" },
    { ACQ_ADC_SCLK, "ADC_SCLK" }, { ACQ_ADC_CS, "ADC_CS" }, { ACQ_CH2_SDO, "CH2_SDO" },
    { ACQ_ENC3_A, "ENC3_A" },
    { ACQ_CH1_SDO, "CH1_SDO" }, { ACQ_ENC3_B, "ENC3_B" }, { ACQ_ENC3_SW, "ENC3_SW" },
    { ACQ_BTN_RUN, "BTN_RUN" }, { ACQ_BTN_SINGLE, "BTN_SINGLE" }, { ACQ_BTN_GEN, "BTN_GEN" },
    { ACQ_LED_RUN, "LED_RUN" }, { ACQ_LED_TRIG, "LED_TRIG" }, { ACQ_LED_ARM, "LED_ARM" },
    { ACQ_LINK1_TX, "LINK1_TX" }, { ACQ_LINK1_RX, "LINK1_RX" },
    { 9, "spare" }, { 14, "spare" }, { 21, "spare" }, { 38, "spare" }, { 47, "spare" },
};

*/

void app_main(void)
{
    esp_chip_info_t chip;
    esp_chip_info(&chip);

    uint32_t flash_bytes = 0;
    esp_flash_get_size(NULL, &flash_bytes);

    ESP_LOGI(TAG, "Oscil board 1: acquisition");
    ESP_LOGI(TAG, "cores %d, silicon v%d.%d",
             chip.cores, chip.revision / 100, chip.revision % 100);
    ESP_LOGI(TAG, "flash %" PRIu32 " MB", flash_bytes / (1024 * 1024));
    ESP_LOGI(TAG, "psram %u MB", (unsigned)(esp_psram_get_size() / (1024 * 1024)));
    ESP_LOGI(TAG, "tick %d Hz, LINK1 on GPIO%d/%d",
             configTICK_RATE_HZ, ACQ_LINK1_TX, ACQ_LINK1_RX);
    ESP_ERROR_CHECK(oscil_status_init(ACQ_STATUS_RGB));
    ESP_ERROR_CHECK(oscil_status_start_heartbeat(0,16,0)); //green
    ESP_LOGI(TAG,"heartbeat on GPIO%d", ACQ_STATUS_RGB);
    //test_pinwalk(ACQ_PINS, sizeof ACQ_PINS / sizeof ACQ_PINS[0]);
    //test_spi_speed();
    // test_panel();
    //test_adc();
    //test_noise();
    //test_dual();
    //test_burst();
    esp_err_t e = nvs_flash_init();                       // calibration lives in NVS
    if (e == ESP_ERR_NVS_NO_FREE_PAGES || e == ESP_ERR_NVS_NEW_VERSION_FOUND) {
        ESP_ERROR_CHECK(nvs_flash_erase());
        e = nvs_flash_init();
    }
    ESP_ERROR_CHECK(e);
    cal_load();                                           // nominal until calibrated

    testsig_start(47, 1000);        // bench signal on header 28 until board 3 exists
    ESP_ERROR_CHECK(acq_start());
    //test_link_loop();
    //test_cal(0);                        // CH1
    //test_cal(1);                        // CH2
}

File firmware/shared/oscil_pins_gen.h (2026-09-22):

#pragma once
// Board 3, generator. Source of truth: hardware/docs/pin-map.md
// D0-D7 are contiguous in GPIO_OUT so all eight bits change in one write.

#define GEN_DAC_D0         4  // header 4, LSB
#define GEN_DAC_D1         5  // header 5
#define GEN_DAC_D2         6  // header 6
#define GEN_DAC_D3         7  // header 7
#define GEN_DAC_D4         8  // header 12
#define GEN_DAC_D5         9  // header 15
#define GEN_DAC_D6        10  // header 16
#define GEN_DAC_D7        11  // header 17, MSB
#define GEN_DAC_SHIFT      4  // D0's GPIO number
#define GEN_DAC_MASK   (0xFFu << GEN_DAC_SHIFT)

// LINK2 from board 2, receive only
#define GEN_LINK2_RX      44  // header 42
#define GEN_STATUS_RGB    48  // header 29, onboard WS2812

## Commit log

2026-09-15 added bill of materials for prototype
    [Oscil_bill_of_materials_bom.xlsx]
2026-09-17 created new dir hardware and kicad init files
    [oscil.kicad_pcb, oscil.kicad_sch]
2026-09-19 Add sheet hierarchy and build log
    [01_power.kicad_sch, 02_afe_ch1.kicad_sch, 03_afe_ch2.kicad_sch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]
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2026-09-20 Power sheet: USB input, rail split, analog LDO
    [01_power.kicad_sch]
2026-09-20 Power sheet: analog rail, rail split, 2.2 V reference
    [01_power.kicad_sch]
2026-09-20 AFE ch1: compensated divider with offset injection
    [02_afe_ch1.kicad_sch]
2026-09-20 AFE ch1: input clamp
    [02_afe_ch1.kicad_sch]
2026-09-20 AFE ch1: unity-gain buffer
    [02_afe_ch1.kicad_sch]
2026-09-21 AFE channel 1: divider, compensation, clamp, buffer, filter
    [02_afe_ch1.kicad_sch, oscil.kicad_sch]
2026-09-21 AFE channel 2: copy of channel 1
    [03_afe_ch2.kicad_sch, oscil.kicad_sch]
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2026-09-21 init acq board, decided on pin maps for mcu 1,2,3 and edited esp32 symbol
    [04_acq.kicad_sch]
2026-09-21 Acquisition sheet: ADC pair, module, front panel
    [02_afe_ch1.kicad_sch, 04_acq.kicad_sch, oscil.kicad_sch]
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2026-09-21 Display sheet: panel connector, touch, backlight
    [05_display.kicad_sch, oscil.kicad_sch]
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2026-09-21 Generator sheet: R-2R ladder and output stage
    [06_gen.kicad_sch, oscil.kicad_sch]
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2026-09-22 Add final Rev A schematic PDF and edited footprints
    [01_power.kicad_sch, 02_afe_ch1.kicad_sch, 03_afe_ch2.kicad_sch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]
2026-09-22 updated bom
    [Oscil_bill_of_materials_bom.xlsx]
2026-09-22 replaced svg with svg with backgroudn included
    [oscil.kicad_sch]
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2026-09-22 acq: add status LED heartbeat on GPIO48
    Bit-banged WS2812 driver using the CPU cycle counter. Green 50 ms blink every second; FreeRTOS task pinned to core 0.
2026-09-23 tested mcu's with heartbeat task (blinking the ws2812 led) for all three, updated build log
2026-09-23 pin walk on board 1 with analyzer captures, readme progress table updated, build log updated
2026-09-23 board 2 pin walk, 26 pins verified; build log tables and captures
2026-09-23 Step 04 done: board 3 pin walk, all 61 pins on three boards verified
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2026-09-24 docs: step 05 SPI speed test results, 919 kSa/s at 26.67 MHz, dual line works
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2026-09-25 acq: move LED_TRIG from GPIO47 to GPIO2 so the panel LEDs sit on adjacent headers
    [04_acq.kicad_sch]
2026-09-25 acq: panel driver, 1 kHz polled debounce for buttons, LED control, events on a queue
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2026-09-25 acq: both ADCs on one SPI2 clock and CS, CH2 data to GPIO11; encoders regrouped onto headers 4-12
    [04_acq.kicad_sch]
2026-09-26 acq: table-driven quadrature decoder for the three encoders in the panel scan
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2026-09-27 acq: ADS7883 frame decode and first-read test, 64-frame average printed as BNC volts, offset calibrated
2026-09-27 docs: first ADC reads, bit-slip traced to the logic analyzer loading SCLK, both channels clean at 10 MHz
2026-09-27 tools: serial capture of a BEGIN..END block, with length and format checks; ADC histogram plot
2026-09-27 acq: noise test at 26.67 MHz comparing SPI modes 0 and 1, paced dump; mode 1 for full speed
    [main.c]
2026-09-27 docs: noise floor 3.9 codes rms at 26.67 MHz, both SPI modes clean, histogram
    [noise.csv]
2026-09-27 shared: ADS7883 frame decode and dual-line bit split in a header with no ESP-IDF includes
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2026-09-28 acq: 1 kHz LEDC test square on a spare pin, from registers
2026-09-28 acq: DMA burst sampler, segmented SPI transfer with GDMA descriptor lists, one interrupt per burst
2026-09-28 acq: burst test at three rates, sample rate checked against the test square
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2026-09-28 docs: DMA burst capture up to 620 kSa/s, rate checked against a 1 kHz reference, mode 0 slipping at 26.67 MHz
    [burst.csv]
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2026-09-28 docs: burst capture and dead time, continuous DMA ring checked against the TRM
2026-09-28 acq: acquisition task on core 1, capture, trigger, min/max frame, RUN/STOP/SINGLE, AUTO fallback
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2026-09-28 shared: UART driver from the registers, interrupt-driven with ring buffers, link layer on top
2026-09-28 acq: UART loopback test, 15,600 frames at 2 Mbaud with zero errors
    [main.c]
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2026-09-28 acq: send waveform frames and panel events over LINK1, accept settings, report run state
2026-09-28 display: receive LINK1 frames, print keys and state, ping round trip, one settings change
2026-09-28 docs: board 1 to board 2 link, 31.8 frames/s with zero errors, bench photo and demo video
2026-09-28 bom: rev 0.3, resistor kit and second breadboard kit, substitutions for values the kit lacks
    [Oscil_bill_of_materials_bom.xlsx]
2026-09-28 docs: display breakouts soldered and checked, Adafruit breakout mapped against its schematic
2026-09-29 docs: display backlight at 40 mA from the XL6009 boost, 100R sense resistor, breakout clamp stays below threshold
2026-09-29 hardware: display sheet relabelled to the new LCD pin order, schematic exports regenerated
    [05_display.kicad_sch]
2026-09-29 display: RGB panel driver from a PSRAM framebuffer, colour bar, bit-line and border test patterns
2026-09-30 docs: RGB panel working, breakout boost back-fed from the 3.3V pad, PWM grounded to hold it off
2026-09-30 hardware: generator ladder all 10k, R as parallel pairs, filter corner now 33 kHz; schematic exports regenerated
    [06_gen.kicad_sch, Oscil_bill_of_materials_bom.xlsx]
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2026-10-01 docs: LVGL hello screen, R7 stuck high traced to shifted jumpers
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2026-10-01 shared: UART RX at interrupt level 3, FIFO threshold 32, reset the RX FIFO on overflow
    [oscil_uart.c]
2026-10-01 docs: live scope view, link overflow under display load traced and fixed
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2026-10-02 hardware: bulk decoupling on the analog rail and ADC VDD, VREF filter, analog parts on +3V3_A
    [01_power.kicad_sch]
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2026-10-02 hardware: 220R series on each link line, analog decoupling notes
    [01_power.kicad_sch, 04_acq.kicad_sch, 05_display.kicad_sch]
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2026-10-03 docs: settings and calibration, calibrated test square, front end off the overheating power module
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2026-10-03 firmware: 16 MB partition table on all boards, two 4 MB OTA slots, storage, app rollback
    [partitions.csv]
2026-10-03 display: reboot into OTA mode before downloading, self-test new firmware, SYS update panel
    [main.c]
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2026-10-03 docs: device sign-in, session recovery and wrong-password results
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2026-10-13 bom: fix ESP32-S3, FNIRSI and FX2LP links, make kit links clickable
